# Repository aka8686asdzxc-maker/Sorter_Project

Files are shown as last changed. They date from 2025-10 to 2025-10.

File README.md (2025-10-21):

# 🧠 Sorter_Project  
Arduino MEGA + HuskyLens Pro 기반 QR 인식 분류 시스템

---

## 📌 프로젝트 개요
본 프로젝트는 HuskyLens Pro AI 카메라와 서보 모터, 컨베이어 시스템을 이용하여  
제품의 QR 코드 인식 및 자동 분류를 수행하는 소형 물류 자동화 모델입니다.  
주요 기능은 다음과 같습니다.

- 📷 QR 인식   
- 🎯 카메라 틸트(상하) 제어를 통한 스캔 범위 확장  
- ⚙️ 컨베이어 라인을 통한 자동 분류    

---

## ⚙️ 사용 부품
| 구분 | 부품명 | 설명 |
|---|---|---|
| 🧩 마이크로컨트롤러 | Arduino MEGA 2560 | 전체 시스템 제어 |
| 👁️ 비전 센서 | HuskyLens Pro | QR 코드 인식 |
| 🔄 서보 모터 | SG90 / MG996R | 카메라 상하 각도 제어 (틸트 기능) |
| 🚚 컨베이어 | DC 모터 + 드라이버 | 제품 이송 |
| 🔋 전원 | SMPS 12V / 24V | 시스템 전원 공급 |

---

## 📂 코드 구성

| 구분 | 설명 | 링크 |
|---|---|---|
| 🎯 Tilt + QR 코드 | 카메라 각도(상하) 틸트를 조정하며 QR을 스캔하고, 인식된 ID(1~3)에 따라 동작 제어 | [열기](./tilt_qr/tilt_qr.ino) |
| ⚙️ Conveyor Only | QR 없이 강제로 분류 ID를 설정하여 테스트 | [열기](./conveyor_only/conveyor_only.ino) |

---
---

## 🧱 모델링 파일 (SolidWorks)

📂 [모델 폴더 보기](./model)

폴더에는 전체 설계 모델링 파일이 **압축 형태로 포함**되어 있습니다.  
모든 부품은 **SolidWorks 2023** 버전으로 제작되었으며,  
일부 주요 부품은 **3D 프린터를 활용해 실제 출력**되었습니다.  

📦 [Sorter_Frame_v1.zip 다운로드 (Google Drive)](https://drive.google.com/file/d/16qrcr41eieWnhJ2iXqQJ7fa6UanfB9HN/view?usp=sharing)

---

## 💰 예산 내역

| 구분 | 품목 | 수량 | 단가(₩) | 금액(₩) | 비고 |
|---|---|---|---|---|---|
| 💻 마이크로컨트롤러 | Arduino MEGA 2560 | 1 | 30,000 | 30,000 | 메인 제어용 |
| 👁️ 비전 센서 | HuskyLens Pro | 1 | 100,000 | 100,000 | QR 인식 |
| ⚙️ 구동부 | 리니어 액추에이터 | 2 | 30,000 | 60,000 | 분류 동작 |
| 🚚 구동부 | DC 모터 + 컨베이어 | 2 | 50,000 | 100,000 | 이송용 |
| 🔋 전원부 | SMPS 24V | 1 | 50,000 | 50,000 | 전원 공급 |
| 🧱 구조물 | 알루미늄 프로파일 | - | 50,000 | 50,000 | 프레임 제작 |
| 🔧 기타 | 배선, 단자대, 브라켓, 모터 드라이버 등등 | - | 110,000 | 110,000 | 소모품 및 구동용품 |
| **총합** |  |  |  | **500,000원 (약 50만 원)** |  |

> 💬 전체 예산은 약 **50만 원**,  
> 주로 구동부와 구조물 제작에 비용이 집중되었습니다.  
---

## 🚀 실행 방법

1️⃣ **Arduino IDE**를 실행하고, 보드를 `Arduino MEGA 2560`으로 설정합니다.  
2️⃣ **HuskyLens 라이브러리**를 설치합니다.  
3️⃣ 각 모듈의 `.ino` 파일을 업로드합니다.  
4️⃣ 전원을 연결하면 자동 분류 시스템이 동작합니다.

---

## 🧾 제작 정보

- 👨‍💻 제작자: **aka6866asdzzxc-maker (김기호 외 팀원)**  
- 🏫 소속: **한국폴리텍 인천캠퍼스 메카트로닉스과**  
- 🧠 프로젝트명: **Sorter_Project**  
- 🛠️ 개발 환경: Arduino IDE + SolidWorks + GitHub  

---

## 💡 Tip

> 📁 `code/` 폴더에는 아두이노 코드,  
> 📁 `model/` 폴더에는 SolidWorks 모델링 파일,  
> 📁 `budget/` 폴더에는 예산 엑셀 파일이 포함되어 있습니다.  
>
> 추후 깃허브 내 **QR 코드 링크**를 통해 코드 및 자료를 바로 열람할 수 있습니다.

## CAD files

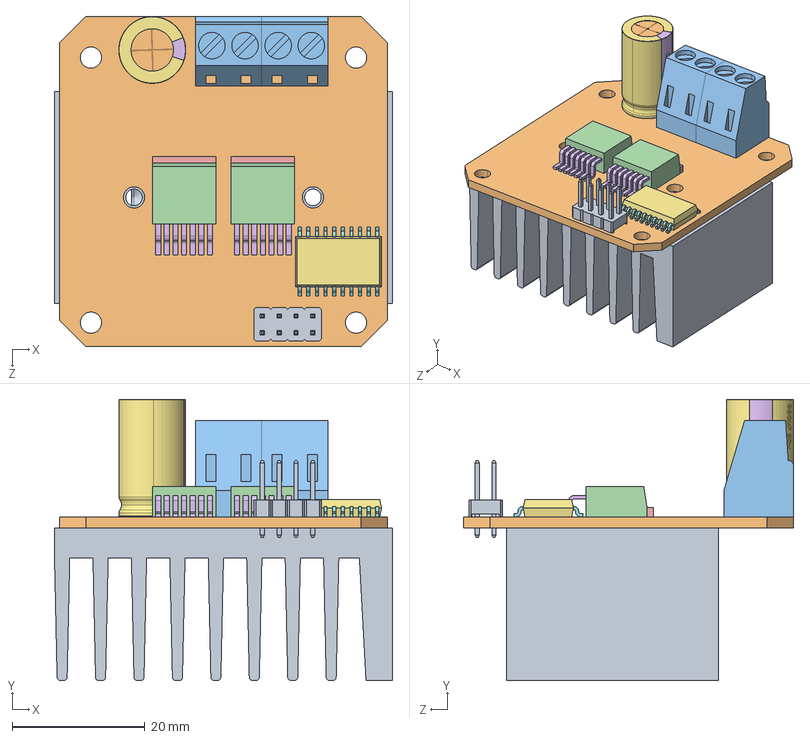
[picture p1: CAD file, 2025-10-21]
model/BTS7960 43A HIGH POWER H BRIDGE MODULE step.STEP
51.0 x 42.4 x 49.8 mm
HEATSINK, BTS7960 43A HIGH POWER H BRIDGE MODULE.STEP
PCB, BTS7960 43A HIGH POWER H BRIDGE MODULE.STEP
EUROSTYLE TERMINAL BLOCK 2 POS 5.0 MM RA PLUG, BTS7960 43A HIGH POWER H BRIDGE MODULE.STEP x 2
BTN7960 IC, BTS7960 43A HIGH POWER H BRIDGE MODULE.STEP x 2
NXP 74HC244D, BUFFER AND LINE DRIVER, BTS7960 43A HIGH POWER H BRIDGE MODULE.STEP
8 PIN HEADER, IC, BTS7960 43A HIGH POWER H BRIDGE MODULE.STEP
ALUMINUM ELECTROLYTIC CAPACITOR, 330 uF, BTS7960 43A HIGH POWER H BRIDGE MODULE.STEP

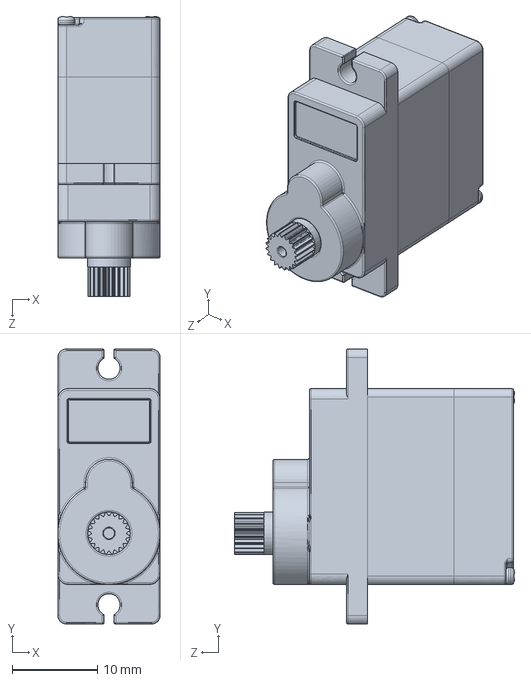
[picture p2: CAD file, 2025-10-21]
model/SG90_Servo_Motor.stp.SLDPRT
12.0 x 32.3 x 32.9 mm

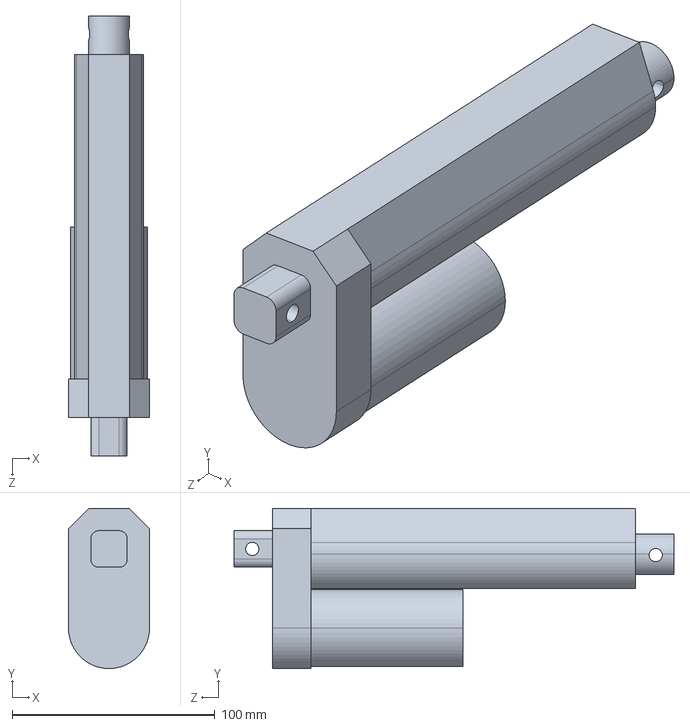
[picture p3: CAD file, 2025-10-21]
model/리니어.STEP
40.0 x 79.0 x 217.0 mm

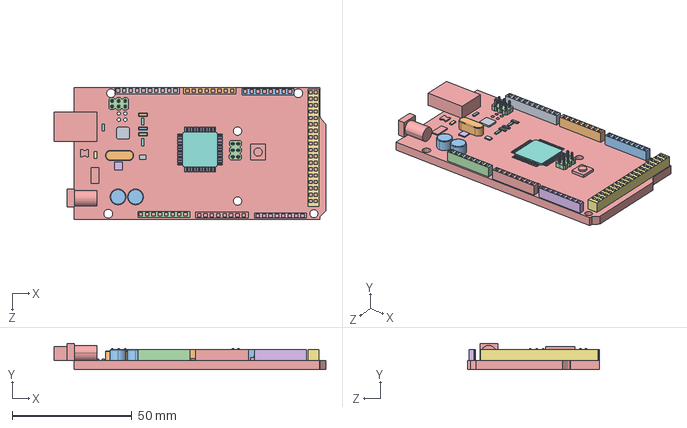
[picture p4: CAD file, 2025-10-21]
model/Adruino Mega step.STEP
113.5 x 10.9 x 55.1 mm

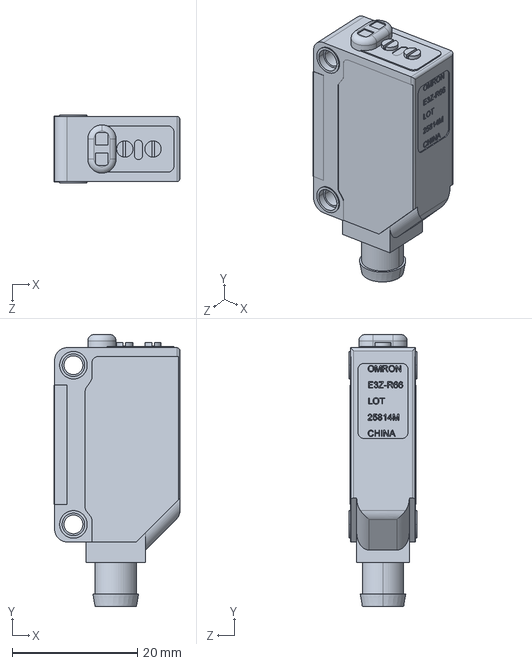
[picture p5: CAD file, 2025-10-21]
model/OMRON E3Z-R66_LOT 25814M step.STEP
20.1 x 43.4 x 10.8 mm

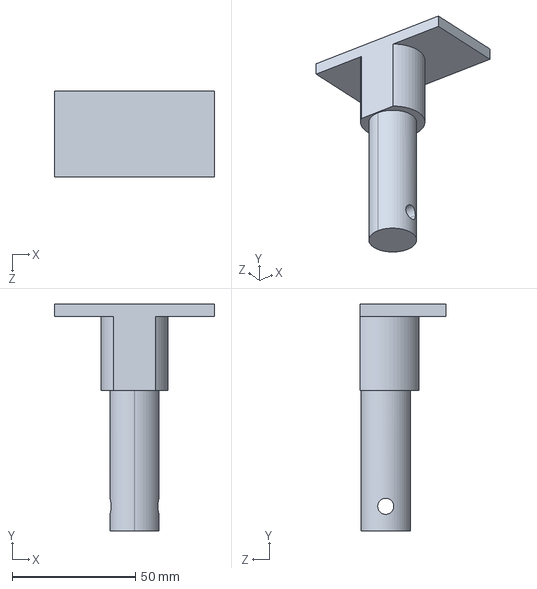
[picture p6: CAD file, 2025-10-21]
model/리니어 대가리.STEP
65.0 x 92.0 x 35.0 mm

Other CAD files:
model/PCB, BTS7960 43A HIGH POWER H BRIDGE MODULE.STEP_4.STEP.SLDPRT
model/TCRT5000 v1.step_1.STEP.SLDPRT
model/리니어 대가리.SLDPRT
model/리니어.SLDPRT

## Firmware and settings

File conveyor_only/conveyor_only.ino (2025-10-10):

/*
========================================
 Arduino MEGA - Conveyor Only Test Code
----------------------------------------
- QR 없이도 분기 테스트 가능 (FORCED_ID로 선택)
- PS1 감지 → Belt1 이송 → PS2 감지 후 분기 동작
- 바닥(PS3/4/5) 감지되면 정지 후 재무장
========================================
*/

// ====== 핀맵 ======
const int B1_EN_R=26, B1_EN_L=27, B1_RPWM=6;      // Belt1
const int B2_EN_R=24, B2_EN_L=25, B2_RPWM=10;     // Belt2
const int B2_LPWM_UNUSED=46;                      // 사용 안함(LOW 고정)

const int L1_EN_R=12, L1_EN_L=13, L1_RPWM=9,  L1_LPWM=11; 
const int L2_EN_R=22, L2_EN_L=23, L2_RPWM=3,  L2_LPWM=4;

const int PS1=30, PS2=31, PS3=32, PS4=33, PS5=34; // 포토센서 (NPN/OC → LOW)
const int LED_R=37, LED_G=38;                     // 상태 LED(선택)

// ====== 파라미터 ======
const uint8_t SPEED_BELT=230, SPEED_LIN=230;
const unsigned T_BELT1_A=4000, T_BELT1_B=4000;
const unsigned T_BELT2_ID1=1100, T_BELT2_ID2=2225, T_BELT2_ID3=5000;
const unsigned T_LIN_FWD=5000, T_LIN_REV=5000;
const unsigned LOCKOUT_MS=1200;                   // 디바운스/락아웃

// ====== 테스트용 강제 분기 (1/2/3 중 골라서 사용) ======
const int FORCED_ID = 1; // ← 필요에 따라 1, 2, 3으로 바꿔 테스트
int lastQR = FORCED_ID;

// ====== 유틸 ======
void ledOff(){ pinMode(LED_R,OUTPUT); pinMode(LED_G,OUTPUT); digitalWrite(LED_R,LOW); digitalWrite(LED_G,LOW); }
bool stableLow(int pin){ const int N=25; int low=0; for(int i=0;i<N;i++){ if(digitalRead(pin)==LOW) low++; delay(2);} return (low>=23); }
bool stableHigh(int pin){ const int N=25; int hi=0; for(int i=0;i<N;i++){ if(digitalRead(pin)==HIGH) hi++; delay(2);} return (hi>=23); }
bool fastLow(int pin){ return (digitalRead(pin)==LOW); }

bool waitDetectLow(int pin){
  unsigned long lastTrig=0; bool last=false;
  while(true){
    bool s=stableLow(pin); unsigned long now=millis();
    if(s!=last && (now-lastTrig)>=LOCKOUT_MS){ last=s; lastTrig=now; if(s) return true; }
    delay(2);
  }
}

bool waitAllClear(const int pins[], int cnt){
  unsigned long t0=0;
  while(true){
    bool ok=true;
    for(int i=0;i<cnt;i++){ if(!stableHigh(pins[i])){ ok=false; break; } }
    if(ok){ if(t0==0) t0=millis(); if(millis()-t0>=50) return true; }
    else t0=0;
    delay(5);
  }
}

bool anyPS345(){ return fastLow(PS3) || fastLow(PS4) || fastLow(PS5); }

// ====== 모터 제어 ======
inline void belt1_on(){ digitalWrite(B1_EN_R,HIGH); digitalWrite(B1_EN_L,HIGH); analogWrite(B1_RPWM,SPEED_BELT); }
inline void belt1_off(){ analogWrite(B1_RPWM,0); digitalWrite(B1_EN_R,LOW); digitalWrite(B1_EN_L,LOW); }
inline void belt2_on(){ digitalWrite(B2_EN_R,HIGH); digitalWrite(B2_EN_L,HIGH); analogWrite(B2_RPWM,SPEED_BELT); }
inline void belt2_off(){ analogWrite(B2_RPWM,0); digitalWrite(B2_EN_R,LOW); digitalWrite(B2_EN_L,LOW); }

void linear1_forward(){ digitalWrite(L1_EN_R,HIGH); digitalWrite(L1_EN_L,HIGH); analogWrite(L1_RPWM,SPEED_LIN); analogWrite(L1_LPWM,0); }
void linear1_reverse(){ analogWrite(L1_RPWM,0); analogWrite(L1_LPWM,SPEED_LIN); }
void linear1_stop(){ analogWrite(L1_RPWM,0); analogWrite(L1_LPWM,0); digitalWrite(L1_EN_R,LOW); digitalWrite(L1_EN_L,LOW); }

void linear2_forward(){ digitalWrite(L2_EN_R,HIGH); digitalWrite(L2_EN_L,HIGH); analogWrite(L2_RPWM,SPEED_LIN); analogWrite(L2_LPWM,0); }
void linear2_reverse(){ analogWrite(L2_RPWM,0); analogWrite(L2_LPWM,SPEED_LIN); }
void linear2_stop(){ analogWrite(L2_RPWM,0); analogWrite(L2_LPWM,0); digitalWrite(L2_EN_R,LOW); digitalWrite(L2_EN_L,LOW); }

void allStop(){ belt1_off(); belt2_off(); linear1_stop(); linear2_stop(); ledOff(); }

// ====== 바닥 감지 → 정지 → 재무장 ======
void waitAnyBottomThenRearm(){
  while(!anyPS345()) delay(1);     // 빠르게 감시
  allStop();
  const int END_PINS[]  = {PS3, PS4, PS5};
  const int TRIG_PINS[] = {PS1, PS2};
  waitAllClear(END_PINS, 3);
  waitAllClear(TRIG_PINS, 2);
}

// ====== 사이클 ======
void runOneCycle(){
  // 1) 투입 감지 (PS1)
  waitDetectLow(PS1);
  belt1_on(); delay(T_BELT1_A); belt1_off(); delay(150);

  // 2) (QR 대신) 고정 분기로 설정
  lastQR = FORCED_ID;

  // 3) 추가 이송 후 분기 지점(PS2) 대기
  belt1_on(); delay(T_BELT1_B); belt1_off();
  waitDetectLow(PS2);

  // 4) 분기 동작
  if (lastQR==1){
    belt2_on(); delay(T_BELT2_ID1); belt2_off(); delay(150);
    linear1_forward(); delay(T_LIN_FWD);
    linear1_reverse(); delay(T_LIN_REV);
    linear1_stop();
  } else if (lastQR==2){
    belt2_on(); delay(T_BELT2_ID2); belt2_off(); delay(150);
    linear2_forward(); delay(T_LIN_FWD);
    linear2_reverse(); delay(T_LIN_REV);
    linear2_stop();
  } else {
    belt2_on(); delay(T_BELT2_ID3); belt2_off();
  }

  // 5) 바닥 센서 감지 후 재무장
  waitAnyBottomThenRearm();
}

// ====== 초기화 ======
void setup(){
  Serial.begin(115200);

  pinMode(B1_EN_R,OUTPUT); pinMode(B1_EN_L,OUTPUT); pinMode(B1_RPWM,OUTPUT);
  pinMode(B2_EN_R,OUTPUT); pinMode(B2_EN_L,OUTPUT); pinMode(B2_RPWM,OUTPUT);
  pinMode(B2_LPWM_UNUSED,OUTPUT); digitalWrite(B2_LPWM_UNUSED,LOW);

  pinMode(L1_EN_R,OUTPUT); pinMode(L1_EN_L,OUTPUT); pinMode(L1_RPWM,OUTPUT); pinMode(L1_LPWM,OUTPUT);
  pinMode(L2_EN_R,OUTPUT); pinMode(L2_EN_L,OUTPUT); pinMode(L2_RPWM,OUTPUT); pinMode(L2_LPWM,OUTPUT);

  pinMode(PS1,INPUT_PULLUP); pinMode(PS2,INPUT_PULLUP);
  pinMode(PS3,INPUT_PULLUP); pinMode(PS4,INPUT_PULLUP); pinMode(PS5,INPUT_PULLUP);

  pinMode(LED_R,OUTPUT); pinMode(LED_G,OUTPUT); ledOff();

  allStop();
  Serial.println(F("✅ Conveyor-only ready. Waiting PS1..."));
}

void loop(){ runOneCycle(); }

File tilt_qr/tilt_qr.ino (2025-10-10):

/*
==========================================
 Arduino MEGA + HuskyLens QR Test Code
==========================================
 기능:
  - 서보 스윙으로 QR 코드 탐색
  - 인식된 ID(1~3)에 따라 LED 색상 표시
  - QR 인식 실패 시 빨간 LED 점멸

 작성자: aka6866asdzxc-maker
==========================================
*/

#include <Wire.h>
#include "HUSKYLENS.h"
#include <Servo.h>

// ====== 핀 설정 ======
const int LED_R = 37;   // 빨강 LED
const int LED_G = 38;   // 초록 (파랑 대체)
const int SERVO_PIN = 28; // 서보 제어핀

// ====== 서보 파라미터 ======
const int SERVO_CENTER = 100;    // 중앙 각도
const int SERVO_SWING_DEG = 60;  // 좌우 회전 범위
const int SERVO_STEP_MS = 80;    // 이동 속도 (ms/step)
const int SCAN_CYCLES = 3;       // 탐색 반복 횟수

// ====== 전역 변수 ======
HUSKYLENS husky;
Servo gate;
int lastQR = 0;

// ====== LED 제어 ======
void ledOff() {
  digitalWrite(LED_R, LOW);
  digitalWrite(LED_G, LOW);
}

void ledBlue3s() { // QR 인식 성공
  digitalWrite(LED_R, LOW);
  digitalWrite(LED_G, HIGH);
  delay(3000);
  ledOff();
}

void ledRedBlink4x() { // 인식 실패
  for (int i = 0; i < 4; i++) {
    digitalWrite(LED_R, HIGH);
    digitalWrite(LED_G, LOW);
    delay(400);
    digitalWrite(LED_R, LOW);
    delay(400);
  }
  ledOff();
}

// ====== QR 인식 함수 ======
bool checkQR() {
  if (husky.request() && husky.available()) {
    while (husky.available()) {
      HUSKYLENSResult r = husky.read();
      if (r.ID >= 1 && r.ID <= 3) {
        lastQR = r.ID;
        return true;
      }
    }
  }
  return false;
}

// ====== 서보 스윙으로 QR 탐색 ======
bool servoScanForQR(int cycles, int center, int swingDeg, int stepMs) {
  int half = swingDeg / 2;
  int a = center - half;
  int b = center + half;

  gate.write(center);
  delay(200);

  for (int k = 0; k < cycles; k++) {
    // 오른쪽으로 회전
    for (int d = center; d <= b; d++) {
      gate.write(d);
      delay(stepMs);
      if (checkQR()) return true;
    }
    // 왼쪽으로 회전
    for (int d = b; d >= a; d--) {
      gate.write(d);
      delay(stepMs);
      if (checkQR()) return true;
    }
    // 다시 중앙으로 복귀
    for (int d = a; d <= center; d++) {
      gate.write(d);
      delay(stepMs);
      if (checkQR()) return true;
    }
  }

  gate.write(center);
  return false;
}

// ====== 초기화 ======
void setup() {
  Serial.begin(115200);
  pinMode(LED_R, OUTPUT);
  pinMode(LED_G, OUTPUT);
  ledOff();

  gate.attach(SERVO_PIN);
  gate.write(SERVO_CENTER);

  Wire.begin();
  if (!husky.begin(Wire)) {
    Serial.println(F("⚠️ HuskyLens 초기화 실패 (I2C)"));
  } else {
    Serial.println(F("✅ HuskyLens 연결 완료"));
  }

  Serial.println(F("=== Tilt+QR Scan Ready ==="));
}

// ====== 메인 루프 ======
void loop() {
  lastQR = 0;
  bool got = servoScanForQR(SCAN_CYCLES, SERVO_CENTER, SERVO_SWING_DEG, SERVO_STEP_MS);

  if (got) {
    Serial.print(F("[QR] 인식 성공 → ID="));
    Serial.println(lastQR);

    if (lastQR == 1 || lastQR == 2) ledBlue3s();
    else ledRedBlink4x();

  } else {
    Serial.println(F("[QR] 인식 실패"));
    ledRedBlink4x();
  }

  delay(1000); // 다음 스캔까지 대기
}
/*
==========================================
 Arduino MEGA + HuskyLens QR Test Code
==========================================
 기능:
  - 서보 스윙으로 QR 코드 탐색
  - 인식된 ID(1~3)에 따라 LED 색상 표시
  - QR 인식 실패 시 빨간 LED 점멸

 작성자: aka6866asdzxc-maker
==========================================
*/

#include <Wire.h>
#include "HUSKYLENS.h"
#include <Servo.h>

// ====== 핀 설정 ======
const int LED_R = 37;   // 빨강 LED
const int LED_G = 38;   // 초록 (파랑 대체)
const int SERVO_PIN = 28; // 서보 제어핀

// ====== 서보 파라미터 ======
const int SERVO_CENTER = 100;    // 중앙 각도
const int SERVO_SWING_DEG = 60;  // 좌우 회전 범위
const int SERVO_STEP_MS = 80;    // 이동 속도 (ms/step)
const int SCAN_CYCLES = 3;       // 탐색 반복 횟수

// ====== 전역 변수 ======
HUSKYLENS husky;
Servo gate;
int lastQR = 0;

// ====== LED 제어 ======
void ledOff() {
  digitalWrite(LED_R, LOW);
  digitalWrite(LED_G, LOW);
}

void ledBlue3s() { // QR 인식 성공
  digitalWrite(LED_R, LOW);
  digitalWrite(LED_G, HIGH);
  delay(3000);
  ledOff();
}

void ledRedBlink4x() { // 인식 실패
  for (int i = 0; i < 4; i++) {
    digitalWrite(LED_R, HIGH);
    digitalWrite(LED_G, LOW);
    delay(400);
    digitalWrite(LED_R, LOW);
    delay(400);
  }
  ledOff();
}

// ====== QR 인식 함수 ======
bool checkQR() {
  if (husky.request() && husky.available()) {
    while (husky.available()) {
      HUSKYLENSResult r = husky.read();
      if (r.ID >= 1 && r.ID <= 3) {
        lastQR = r.ID;
        return true;
      }
    }
  }
  return false;
}

// ====== 서보 스윙으로 QR 탐색 ======
bool servoScanForQR(int cycles, int center, int swingDeg, int stepMs) {
  int half = swingDeg / 2;
  int a = center - half;
  int b = center + half;

  gate.write(center);
  delay(200);

  for (int k = 0; k < cycles; k++) {
    // 오른쪽으로 회전
    for (int d = center; d <= b; d++) {
      gate.write(d);
      delay(stepMs);
      if (checkQR()) return true;
    }
    // 왼쪽으로 회전
    for (int d = b; d >= a; d--) {
      gate.write(d);
      delay(stepMs);
      if (checkQR()) return true;
    }
    // 다시 중앙으로 복귀
    for (int d = a; d <= center; d++) {
      gate.write(d);
      delay(stepMs);
      if (checkQR()) return true;
    }
  }

  gate.write(center);
  return false;
}

// ====== 초기화 ======
void setup() {
  Serial.begin(115200);
  pinMode(LED_R, OUTPUT);
  pinMode(LED_G, OUTPUT);
  ledOff();

  gate.attach(SERVO_PIN);
  gate.write(SERVO_CENTER);

  Wire.begin();
  if (!husky.begin(Wire)) {
    Serial.println(F("⚠️ HuskyLens 초기화 실패 (I2C)"));
  } else {
    Serial.println(F("✅ HuskyLens 연결 완료"));
  }

  Serial.println(F("=== Tilt+QR Scan Ready ==="));
}

// ====== 메인 루프 ======
void loop() {
  lastQR = 0;
  bool got = servoScanForQR(SCAN_CYCLES, SERVO_CENTER, SERVO_SWING_DEG, SERVO_STEP_MS);

  if (got) {
    Serial.print(F("[QR] 인식 성공 → ID="));
    Serial.println(lastQR);

    if (lastQR == 1 || lastQR == 2) ledBlue3s();
    else ledRedBlink4x();

  } else {
    Serial.println(F("[QR] 인식 실패"));
    ledRedBlink4x();
  }

  delay(1000); // 다음 스캔까지 대기
}

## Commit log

2025-10-10 Add tilt_qr.ino
    Added Arduino MEGA + HuskyLens QR test code
2025-10-10 Add conveyor_only.ino
2025-10-21 Delete Sorter_Frame.SLDASM
    Remove misplaced Sorter_Frame.SLDASM (moved to /model)
    [Sorter_Frame.SLDASM]
2025-10-21 Add assembly bundle: model/Sorter_Frame_v1.zip
    SolidWorks 전체 조립 파일 업로드 (25MB 이하)
    - 포함 내용: 프레임, 컨베이어, 센서 브라켓 등 주요 구성품
    - SolidWorks 2023 이상 버전에서 열 수 있음
    [Adruino Mega step.STEP, BTS7960 43A HIGH POWER H BRIDGE MODULE step.STEP, OMRON E3Z-R66_LOT 25814M step.STEP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]
